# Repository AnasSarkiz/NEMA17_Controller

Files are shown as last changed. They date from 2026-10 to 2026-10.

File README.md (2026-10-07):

# NEMA14 USB-C PD controller

A two-layer tscircuit **hardware prototype** for the STEPperONLINE 14HM11-0404S, using **CH32X035G8U6**, two separate USB-C receptacles, and four mounting holes. Manufacturing release is blocked until the motor's rear geometry is verified and the prototype is tested. See `artifacts/drc-report.json` for the current routed-board checks; a generated Gerber ZIP is not a release approval.

| Item | Design |
| --- | --- |
| Motor | 35 × 35 × 28 mm, bipolar, 0.9°, 0.4 A/phase, 10 V, 11 N·cm — specifications from the supplied product listing |
| Board | 35 × 35 mm, two copper layers, 1.6 mm FR-4; all components assembled on top |
| USB-C placement | PD opening flush with left edge; data opening flush with right edge; pads and shell anchors inside PCB |
| Mounting | Four Ø3.2 mm non-plated holes at (±13, ±13) mm; 26 mm square pitch; 5.4 mm square copper/component exclusions |
| MCU | CH32X035G8U6, QFN-28 plus grounded exposed pad; internal oscillator |
| Power USB-C | CH224K fixed request for **15 V**: CFG1 low, CFG2/CFG3 high |
| Computer USB-C | USB 2.0 full-speed D+/D− and two 5.1 kΩ CC pull-downs; USBLC6-2SC6 ESD protection |
| Driver | A4988SETTR-T, fixed 1/16 microsteps, regulated phase current |
| Current | 0.351 A nominal peak; 0.24 Ω sense resistors; 39 kΩ/10 kΩ VREF divider |
| Motor connection | Four plated wire-solder holes: A+, A−, B+, B− |
| Programming | Data USB-C via ROM ISP with 4.7 kΩ BOOT jumper; WCH-LinkE debug pads retained |
| Tools | tscircuit 0.0.2764, CLI 0.1.2261; latest npm versions at setup time, pinned in lockfile |

## View and work on the design

```sh
cd /workspace/NEMA17_Controller
npm ci --legacy-peer-deps --cache /workspace/.npm-cache
npm run dev
npm run check
```

`npm run dev` starts the tscircuit editor. The editor source is `src/board.tsx`; the final, saved copper is `artifacts/board.circuit.json`. Editor autorouting can produce different traces; **do not replace the checked copper without rerunning DRC**. The original tscircuit autorouting, including its diagnosed violations, is retained as `artifacts/autorouted.circuit.json` for comparison.

The routing workflow is recorded in `docs/routing.md`. Render the saved final layout with `npm run render`; this preserves routes. `npm run autoroute` runs tscircuit's local autorouter afresh. The final fallback uses freerouting 2.0.1 and the physically accurate DSN exporter in `scripts/export-supplier-router.py`; both the DSN and SES are saved. Checks run against actual copper, not the existence of a server or a generated file.

## Electrical choices

The A4988 regulates coil current, so 15 V supply does not apply a constant 15 V to the 10 V-rated windings. VREF = 3.3 × 10/(39+10) = 0.6735 V; I_peak = VREF/(8 × 0.24 Ω) = 0.3508 A. The tolerance/engineering allowance estimates 0.3969 A; current and temperature must be measured on a prototype. The motor has 400 full steps/revolution, giving 6,400 commanded microsteps/revolution.

The motor bridge draws only from `PD_VBUS`. Two B5819W Schottky diodes OR `PD_VBUS` and `DATA_VBUS` into a 30 V-rated HT7533-1 3.3 V regulator. This lets the MCU enumerate from the computer alone and prevents 15 V backfeeding into the computer's VBUS. Both ports share signal ground. The linear regulator supplies only logic; motor current bypasses it. Driver SLEEP has a pull-down and ENABLE_N a pull-up, so the bridge remains disabled until firmware deliberately enables it.

Use a USB PD supply advertising a 15 V PDO. The CH224K requests 15 V; it cannot force an unsupported supply to deliver it. CH224K PG is an **active-low** good-power indication. Firmware must also check measured motor voltage before enabling the bridge. DATA_PRESENT permits USB attachment only when computer VBUS is present. See `docs/firmware-interface.md`; no USB motor-control firmware or physical enumeration result is claimed by this hardware-only prototype.

## Rear mounting decision

The supplied listing establishes the motor envelope; it does **not** establish rear screw threads or rear-hole pitch. The [manufacturer drawing](https://www.omc-stepperonline.com/download/14HM11-0404S.pdf) confirms 26 ± 0.2 mm pitch and four M3 threads, minimum 4 mm depth, on the front mounting face; it does not dimension rear attachment holes. The four 26 mm-spaced board holes are provisionally suitable for a separate rear adapter/standoff plate. **They are not asserted to match the motor's rear screws. Do not replace motor end-cap screws or drill the motor from these files.** The mounting drawing explicitly marks the unresolved fit. Rear installation also needs an insulating gap and clearance for motor wiring, any rear shaft/boss, and screw heads. Use an adapter plate after the rear drawing or physical motor is available.

## Cost and release

There are 38 fitted parts and three bare motor/debug/BOOT interfaces, with no purchased PD module, motor-driver module, external crystal, buck inductor, potentiometer, or motor connector. A rough small-volume component allowance is **US$4–7**, excluding PCB, assembly, shipping, motor, and supply. This is an estimate, not a vendor quote or an absolute budget guarantee. Ratings and procurement notes are in `docs/bom.md`.

Before ordering: obtain the motor rear drawing, review the footprint pin numbering and assembly rotations, check the current DRC/short report, then bench-test USB, PD negotiation, disabled start-up, phase current, regeneration, and temperature. The configured install/start instructions are saved as a draft in environment settings; saving that draft does not publish the environment.

## Published project

[tscircuit: NEMA14_CH32X035G8U6](https://tscircuit.com/AnasSarkiz/NEMA14_CH32X035G8U6). GitHub rename to the same exact name is pending repository-administration authorization; see [publishing notes](docs/publishing.md).

## Supplier models and A4 schematics

[Printable A4 schematic](artifacts/schematic-a4.pdf): 9 numbered landscape sheets with chip-purpose notes and every numbered physical pin. All **38/38 fitted components** use exact JLCPCB imports with native land patterns and OBJ/STEP models. Motor/debug/boot connections are bare PCB pads. See [supplier CAD details](docs/supplier-cad.md) and [the import report](artifacts/jlcpcb-import-report.json).

The GitHub repository is currently [AnasSarkiz/NEMA17_Controller](https://github.com/AnasSarkiz/NEMA17_Controller). Its requested rename to `NEMA14_CH32X035G8U6` is blocked by the GitHub integration (HTTP 403); repository settings must apply it. The project/package name is already correct. Supplier CAD URLs use the existing public repository so they load now.

## USB and final validation

[USB programming procedure](docs/usb-programming.md) · [Validation details](docs/validation.md) · [Browser schematic analysis](artifacts/validation/schematic-analysis-ui.png). Both board variants support boot-mode entry through their Data USB-C port; flashing still requires assembled-hardware validation. Current software checks report zero DRC errors/warnings, zero schematic-placement findings and no Gerber shorts. Application firmware remains a separate task.

The public main entry point is `index.circuit.tsx`, which exports the board from `src/board.tsx`. `index.circuit.json` is the checked saved layout; publication refreshes it from `artifacts/board.circuit.json` and includes both JSON files. `tscircuit.config.json` selects the root source entry and saved-layout preview.

Publication uses the CLI build-output option: `tsci push index.circuit.tsx --include-dist`. Before uploading, the script runs `tsci build index.circuit.json` and verifies that `dist/index/circuit.json` equals the checked saved routing.

## Copper and electrical review

The [electrical review](docs/electrical.md) records power-trace widening, filled grounds, the corrected 100 kΩ/10 kΩ motor-voltage divider, copper-thickness requirements, and remaining prototype tests. Run `npm run check:copper` for the actual saved-segment audit. The [machine-readable report](artifacts/trace-width-review.json) distinguishes isolated tracks from parallel ground-plane paths; software checks do not certify hardware operation.

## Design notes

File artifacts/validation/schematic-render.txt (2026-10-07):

> NEMA14_CH32X035G8U6@1.0.6 render
> bun scripts/render.ts --schematic-only

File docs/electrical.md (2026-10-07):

# Electrical design review

A4988 VREF = 3.3 × 10/(39+10) = 0.6735 V; Itrip = VREF/(8 × 0.24) = 0.3508 A. The native 0.24 Ω, 1%, 125 mW resistors dissipate about 29.5 mW nominally. A deliberately expanded 3.465 V rail budget, 1% resistor bounds and a provisional 5% driver allowance estimate 0.3969 A. This is an engineering budget, not a qualified maximum: the actual driver accuracy, ground bounce and sense-track resistance must be measured. The SMF18A clamp still requires regenerative-energy testing.

## Copper review, 2026-10-07

The checked saved layout, rather than nominal JSX settings, was reviewed. Power/motor tracks were widened only when exact imported pad, via and foreign-track geometry retained at least 0.15 mm clearance. Their centerlines were retained. `artifacts/power-copper-adjustments.json` records each width change; `supplier-routing-adjustments.json` replays the complete result from the saved SES import. Ground pours have 0.20 mm clearance, 0.35 mm edge margin, and no unconnected islands. Components remain top-side assembled.

| Copper | Actual saved width / review |
| --- | --- |
| Motor outputs / sense | About 0.28–0.45 mm, including package escapes; screened at 0.40 A peak |
| PD motor supply | 0.30–0.60 mm; 0.75 A input budget, with a verified single-bridge RP2040 branch screened at 0.40 A |
| Logic supply / switching node | Widened where possible; package escapes remain as small as 0.16 mm; 0.15 A rail / 0.20 A switching budget |
| Ground | 0.16–0.45 mm tracks plus filled ground copper; parallel plane paths must be considered, rather than assuming the entire motor return flows down every ground stub |
| USB / other signals | 0.16 mm; width alone does not establish differential impedance or signal integrity |

Copper screening requires **at least 35 μm finished external copper and 17.5 μm internal copper** where applicable, on 1.6 mm FR-4, with at least 20 μm via barrel plating. These are fabrication requirements, not measurements of a manufactured PCB. IPC-2221 equations use k=0.048 externally and 0.024 internally, with a 30 °C rise screening limit. The report includes each actual segment, layer, current budget and temperature estimate. This approximate method does not model enclosure/motor heating, neck heat spreading, switching pulses, vias or ground-plane current sharing.

The largest isolated non-ground trace estimate is 5.2 °C at its assigned budget. Ground traces covered by the same-net pour are explicitly reported as parallel paths; their isolated-track estimate is not a prediction of actual plane temperature. Ground current sharing and regulator/driver temperatures remain bench checks.

## Voltage sensing correction

R_VM_H/R_VM_L is now **100 kΩ/10 kΩ**, replacing 100 kΩ/22 kΩ. It produces 1.364 V at 15 V; the worst resistor-tolerance value is 3.240 V at a 35 V review envelope. The old divider produced 3.606 V at only 20 V, before tolerance, so motor regeneration could overstress the ADC input. This change reuses JLCPCB C25804 and its unchanged native footprint. **Firmware must multiply VM_SENSE voltage by 11**, with calibration as needed. The 35 V arithmetic envelope is not approval to operate the motor bus at 35 V; the intended supply remains 15 V. Rails, TVS energy and component ratings require transient testing.

## Operation review and remaining tests

CH224K requests 15 V with CFG1/2/3 = 0/1/1; PG is active low. A supply must advertise the requested PDO. Driver ENABLE_N has a pull-up, SLEEP has a pull-down, and firmware must keep the bridge disabled until PG and measured VM are valid. Diode ORing separates host VBUS from PD while permitting logic-only USB power. USB/data ground is shared with motor power.

USB programming entry is wired: WCH ROM ISP through PC17/D+ at cold power-up on CH32; RP2040 ROM USB boot through the flash-CS boot jumper and RUN/reset. This has not been demonstrated on physical hardware. USB routes were checked for continuity and shorts, but were not impedance-qualified or accepted as a length-matched differential pair. Reported per-net copper totals contain connector/ESD branches and must not be interpreted as pair skew. Host-only, PD-only and simultaneous-cable tests, both Type-C orientations, repeated enumeration and actual flashing are required.

At first bring-up, keep the motor disconnected, power through a current-limited source, check all rails and confirm disabled outputs. Then verify 15 V PD negotiation/fallback behavior and absence of host backfeed. Measure 3.3 V ripple and load-step response (plus RP2040 1.1 V and crystal startup), flash over USB, measure both phase currents and sense offsets, and exercise stalled/accelerating/stopping motor cases while watching VM overshoot and driver/regulator temperatures. Test at the intended motor/enclosure temperature. The CH32 linear regulator dissipates roughly (14.6−3.3)×I_logic, or about 0.34 W at 30 mA; the 100 mA part rating alone is not a thermal guarantee. The RP2040 buck's switching/input loop and feedback placement require ripple/stability validation.

No motor-control firmware is present. Rear mounting remains unverified because the motor drawing dimensions only the front face. Manufacturer-level A4988 accuracy, CH224K/HT7533 electrical limits and component transient ratings remain purchasing/release checks; direct manufacturer document retrieval was blocked in this environment. Existing pin/reference and supplier evidence is recorded in `docs/sources.md`. **Manufacturing release remains blocked.**

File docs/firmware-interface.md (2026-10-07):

# Firmware interface (hardware contract; implementation pending)

| Signal | CH32X035G8U6 pad | GPIO | Requirement |
| --- | --- | --- | --- |
| STEP | 5 | PA0 | Timer-driven pulses, ≥2 µs high and ≥2 µs low |
| DIR | 6 | PA1 | Hold stable ≥2 µs before STEP edge |
| PD_GOOD | 7 | PA2 | Active-low CH224K PG; pull-up to 3.3 V |
| DATA_PRESENT | 8 | PA3 | 100 kΩ/100 kΩ divider from computer VBUS |
| VM_SENSE | 9 | PA4 | 100 kΩ/10 kΩ divider; 15 V → 1.364 V; ADC full scale is not a safe overvoltage limit |
| ENABLE_N | 14 | PB3 | High disables driver; hardware default high |
| SLEEP | 15 | PB4 | Low disables bridge/charge pump; hardware default low |
| DCK | 24 | PC19 | WCH two-wire programming clock |
| DIO | 25 | PC18 | WCH two-wire programming data |
| USB D− | 26 | PC16 | USBFS native PHY |
| USB D+ | 27 | PC17 | USBFS native PHY |

CH32X035G8U6 uses 3.3 V supply and its internal 48 MHz oscillator. USB firmware must select the MCU's **3.3 V PHY mode**, detect data-port VBUS, and use the native USB pull-up configuration; do not copy a 5 V-only example unchanged. The fixed PD trigger requires no MCU PD stack.

Startup sequence: initialize STEP low, ENABLE_N high, SLEEP low; read voltage and PG; expose USB only with data VBUS present; require an explicit host command; enable only with PG low and motor supply 13.5–16.5 V; raise SLEEP, wait at least 1 ms for the charge pump, then drive ENABLE_N low. A source without a 15 V PDO must leave the motor disabled. Stop on a lost PD contract, USB disconnect, or command watchdog timeout. Never automatically resume motion after reset.

A proposed USB CDC command interface is `STATUS`, `MOVE <signed microsteps> <microsteps/second>`, `STOP`, and `DISABLE`. Use a timer/state machine rather than blocking delays. Limit acceleration and speed through bench testing; winding current and available torque limit the useful rate. This file is a contract for the next firmware task, not tested firmware. WCH provides `EVT/EXAM/USB/USBFS/DEVICE/SimulateCDC` in its CH32X035 SDK; remove the example's USART2 bridge because PA2 is used here for PD power sensing. PA3 is used for computer-VBUS presence.

For factory ROM USB boot entry, see [USB programming](usb-programming.md). This hardware contract does not supply a motor-control application.

Motor voltage conversion: `VM_V = VM_SENSE_V × 11` for the reviewed 100 kΩ/10 kΩ divider. Update/calibrate firmware accordingly; the former ×(122/22) conversion is obsolete.

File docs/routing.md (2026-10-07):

# Saved supplier-footprint routing

The latest native tscircuit autorouter was run and its result is saved as `artifacts/autorouted.circuit.json`. Remaining violations required the authorized Freerouting fallback. `scripts/export-supplier-router.py` exports exact imported polygon, rectangle, pill and circle pads to `supplier-input.dsn`; Freerouting 2.0.1 output is saved in `supplier-board.ses`. `scripts/import-supplier-session.py supplier` converts that session without replacing supplier footprints.

The CH32 board uses two copper layers. The RP2040 board uses top / inner1 ground / inner2 signals / bottom, with no inner1 signal tracks. RP2040 ground fills have 0.20 mm clearance and 0.35 mm edge margin. Ordinary fallback vias are 0.50/0.25 mm. Two RP2040 QSPI escape vias are 0.40/0.20 mm. Only grounded exposed-pad thermal vias may sit inside pads. All fitted components and paste are on top; through-hole USB shield joints require soldering.

Selected final PCB changes from the fallback session are recorded in `supplier-routing-adjustments.json`. These include thermal-pad contact segments, and on RP2040 a 0.10 mm C_DV50 move, neighboring V1V1/QSPI_SD3 trace adjustments and the completed QSPI_SD0 route. No native supplier land pattern was changed. `replay-supplier-adjustments.py` checks each expected before-record before applying the saved adjustment set.

Validate the final `board.circuit.json` with `npm run check`, the native-geometry `verify-connectivity.py`, `tsci check`, and all-layer 100 pixels/mm Gerber shorts analysis. These checks do not establish controlled impedance, EMC, manufacturing fit or tested hardware operation.

The 2026-10-07 power review widened saved track records without changing their paths and refilled grounded copper on all existing layers. Both variants now have ground fills. `review-power-copper.py` performs clearance-constrained widening; `fill-ground.py` refills native-geometry pours; `audit-trace-widths.py` screens the resulting actual segments. Complete SES-to-final changes remain in the replay proof. Rerouting or replay must also recompile and merge current source metadata so the 10 kΩ motor-sense resistor is retained.

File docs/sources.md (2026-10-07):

# Sources and evidence

- Motor requested by user: https://www.omc-stepperonline.com/nema-14-bipolar-0-9deg-11ncm-15-58oz-in-0-4a-10v-35x35x28mm-4-wires-14hm11-0404s . Manufacturer drawing verified: https://www.omc-stepperonline.com/download/14HM11-0404S.pdf . It confirms 0.40 A/phase, 25 Ω ±10%, 24 mH ±20%, 0.9° steps, and front-face 26 ±0.2 mm M3 mounting pitch. Rear attachment dimensions are absent.
- Official WCH SDK: https://github.com/openwch/ch32x035 . Its Snake board embeds a CH32X035G8U6 symbol and QFN28/4×4/0.4/2.6×2.6 footprint.
- Current KiCad symbols: https://gitlab.com/kicad/libraries/kicad-symbols , inspected revision `e1bb0a65cb243525367c5dc7294665b9fd57fc4d`; `MCU_WCH_RiscV/CH32X035G8U6` and `Interface_USB/CH224K` establish pin mapping and package selection.
- Current KiCad footprints: https://gitlab.com/kicad/libraries/kicad-footprints ; `SSOP-10-1EP_3.9x4.9mm_P1mm_EP2.1x3.3mm` and `SOT-89-3` establish the corrected PD and regulator land dimensions.
- Published PD reference: https://github.com/tomorrow56/CH224K_PDDecoy , `toragi/img/04_Schematics.png` independently confirms CC1 pin7 / CC2 pin6. https://github.com/UNIT-Electronics-MX/unit_proto_power_delivery_decoy_ch224k at `36e92b99cba94163813b383ca9a16cd6f7f6ef62` documents CFG1/2/3 = 0/1/1 for 15 V.
- Driver package/pin reference: https://github.com/adafruit/Adafruit-A4988-Breakout-PCB at `f10f6b1d10aeeabc7a4a3445b81925c0a51d0e45`, Eagle A4983_LOGICAL / QFN28_5MM used on that A4988 carrier. Manufacturer A4988 electrical accuracy/rating review remains required before release. Current pads and models come from the genuine JLCPCB import, not this reference footprint.
- USB footprint: https://github.com/KiCad/kicad-footprints/blob/master/Connector_USB.pretty/USB_C_Receptacle_HRO_TYPE-C-31-M-12.kicad_mod . Converted to TSX using the current tscircuit CLI; physically shared USB pads are represented once.
- Freerouting fallback: https://github.com/freerouting/freerouting/releases/tag/v2.0.1 ; Java21-compatible release JAR downloaded over verified HTTPS. The unsupported GUI-only 1.9.0 attempt was abandoned.

Current fitted parts are genuine JLCPCB imports obtained with `tsci import --jlcpcb --download --use-exact-footprint <C-number>`. `src/jlcpcb-catalog.json` records component-to-part mapping, original import hashes and native OBJ/STEP hashes. No fitted part uses a custom replacement footprint. Earlier KiCad/Eagle references establish pin cross-checks only; they do not define the current supplier land patterns.

Current tools: tscircuit 0.0.2764, CLI 0.1.2261, pinned in the lockfile. WCH evaluation-board reference section 5 documents PC17-high cold-start ROM USB programming. RP2040 and AP63203 manufacturer PDFs used for power/boot/reference checks are cached in the RP2040 project's `references/` directory. The AP63203 PDF is DS41326 Rev 3-2, November 2024, including the fixed-output pin map and PCB layout guidance. Additional direct Allegro/Raspberry Pi document retrieval during this review returned HTTP 403; no new manufacturer qualification is claimed from those failed requests.

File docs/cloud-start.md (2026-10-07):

# Cloud startup

Use the existing `/workspace/NEMA17_Controller` and `/workspace/NEMA14_RP2040` checkouts. Install from lockfiles using `npm ci --legacy-peer-deps`; local scripts supply Bun. `scripts/cloud-install.sh` restores Python routing dependencies in `/workspace/.routing-venv`, verifies locked Git dependency source checksums and Freerouting 2.0.1. Retain TLS/checksum checks.

Run TypeScript, source compilation, saved-board build, native physical connectivity and all-layer Gerber shorts checks. The delivery has 351 trace sections/38 fitted supplier models on CH32 and 519 trace sections/61 fitted models on RP2040; DRC errors and warnings are zero. `npm run build` uses saved copper. `npm run autoroute` writes a separate diagnostic result and does not replace delivery copper.

Use `XDG_CONFIG_HOME=/workspace/.config` for authenticated CLI publication. Reuse configured authentication without printing secrets. Exact JLCPCB imports and OBJ/STEP assets are in `imports/supplier/`; CAD viewers load public GitHub URLs. Native A4 drawings have 9 CH32 and 13 RP2040 pages. The supplier report requires the routing Python environment: `/workspace/.routing-venv/bin/python scripts/report-presentation.py`.

`npm run dev -- --port 5173` starts the saved-board preview. `python3 scripts/schematic-review-ui.py` starts the read-only native A4/CLI findings review UI. Check local HTTP endpoints internally; share the public project links. The official IDE saved-JSON schematic pane is disabled and WebGPU is unavailable here. Restart servers in a fresh task.

Both designs remain unassembled prototypes. Rear-motor fit, physical USB flashing, PD/thermal testing and firmware implementation remain outstanding. The manufacturer drawing gives front mounting only; four 26 mm-pitch holes are for an unverified rear adapter. The CH32 GitHub identity remains AnasSarkiz/NEMA17_Controller because its requested rename returned HTTP 403. Environment draft saving does not activate its configuration; review/save/publish in environment settings. Fresh-task restoration has not been independently tested.

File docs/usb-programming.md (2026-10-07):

# USB programming

1. Disconnect both USB-C cables so the MCU is fully unpowered.
2. Short the two bare `J_BOOT` pads with tweezers. `R_USB_BOOT` (4.7 kΩ) pulls PC17/D+ high, following WCH's reference download circuit.
3. Connect the computer to **J_DATA** while holding the short; release it after power-up.
4. Use WCHISPTool's CH32X035 USB download mode to load a compatible application.
5. Remove the short and power-cycle to run the application.

Source: WCH [CH32X035 official EVT](https://github.com/openwch/ch32x035), `EVT/PUB/CH32x035 Evaluation Board Reference-EN.pdf`, section 5, and `EVT/PUB/CH32X035SCH.pdf`. PC17 is physical pad 27; PC16/D− is pad 26. WCH-LinkE pads remain available. The example USB-IAP application is not preloaded; this procedure targets factory ROM ISP. Both power inputs must be disconnected for cold boot.

The **PD port is motor power only**, requesting 15 V. Programming uses the separate **Data USB-C port**. USB ROM entry connections and physical copper continuity have been checked in CAD. Enumeration, boot-ROM PHY operation at the chosen supply, and actual flashing must still be tested on an assembled prototype. No motor-control firmware has been implemented or preloaded. Keep the motor disconnected during the first flashing/rail checks.

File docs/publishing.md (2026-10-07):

# Publishing

Requested name: `NEMA14_CH32X035G8U6` (case retained).

Public registry project: https://tscircuit.com/AnasSarkiz/NEMA14_CH32X035G8U6 . Publish updates with `npm run publish:tscircuit`; CLI login uses `XDG_CONFIG_HOME=/workspace/.config tsci login`. The configuration includes checked copper in `artifacts/board.circuit.json`. The source-rendered registry preview may autoroute differently; use the saved artifact and Gerbers to review manufactured copper.

GitHub: https://github.com/AnasSarkiz/NEMA17_Controller . Renaming to `AnasSarkiz/NEMA14_CH32X035G8U6` remains blocked: GitHub returned HTTP 403, "Resource not accessible by integration", although account access reports administrator permission. The integration credential needs repository Administration write permission, or the owner can rename in repository Settings. After renaming:

```sh
git remote set-url origin https://github.com/AnasSarkiz/NEMA14_CH32X035G8U6.git
git push origin HEAD:main
```

The registry upload is independent; automatic GitHub linking was rejected because the repository is not accessible to the tscircuit GitHub app installation. Both projects are public. Publication does not imply firmware completion, tested electrical behavior, rear mounting compatibility, or manufacturing approval.

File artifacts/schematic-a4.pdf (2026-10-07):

A | A

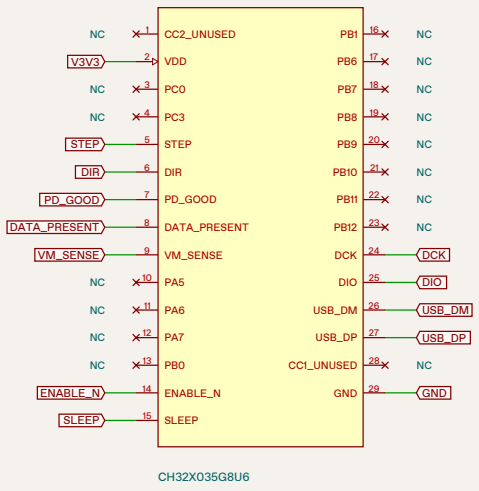
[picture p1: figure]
CC2_UNUSED; VDD; STEP; DIR; PD_GOOD; DATA_PRESENT; VM_SENSE; 14 ENABLE_N; 15 SLEEP; 24 DCK; 25 DIO; 26 USB_DM; 27 USB_DP; 28 CC1_UNUSED; 29 GND; ENABLE_N; SLEEP; DCK; DIO; USB_DM; USB_DP; GND

B | B
C | C
D | D

### U_MCU

## NEMA14_CH32X035G8U6 - USB-C NEMA14 MOTOR CONTROLLER

## COMPONENT PURPOSE

### U_MCU - CH32X035G8U6

USB computer control; generates STEP/DIR. Checks PD voltage before enabling the motor. Internal clock avoids an external crystal.

### U_PD - CH224K

USB-C PD sink requests a 15 V motor supply. PG reports a completed power negotiation.

### U_LDO - HT7533-1

Creates 3.3 V for MCU and driver logic.
Diode OR accepts either USB data power or PD.

### U_DRV - A4988

Two current-regulated bridges drive the coils. STEP/DIR interface; fixed 1/16 microstepping. 0.24 ohm sense resistors set phase current.

### U_ESD - USBLC6-2SC6

Clamps ESD on USB D+ and D- at the data port. VBUS pin references the USB protection diodes.

PD PORT: motor power, 15 V requested. DATA PORT: USB computer control.
Motor: 14HM11-0404S, bipolar, 0.4 A/phase. Prototype: firmware/bench/rear-fit validation pending.

### SHEET 1/9 - U_MCU

Named nets connect across all pages. NC = intentionally unconnected pin.

A | A

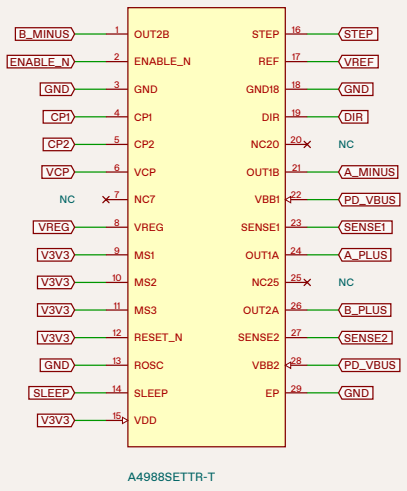
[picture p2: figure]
A4988SETTR-T; OUT2B; ENABLE_N; GND; VCP; VREG; 12 RESET_N; 13 ROSC; 14 SLEEP; 15 VDD; 16 STEP; 17 REF; 18 GND18; 19 DIR; 21 OUT1B; 22 VBB1; 23 SENSE1; 24 OUT1A; 26 OUT2A; 27 SENSE2; 28 VBB2; B_MINUS; SLEEP; STEP; VREF; DIR; A_MINUS; PD_VBUS; SENSE1; A_PLUS; B_PLUS; SENSE2

B | B
C | C
D | D

### U_DRV

## COMPONENT PURPOSE

### U_MCU - CH32X035G8U6

USB computer control; generates STEP/DIR. Checks PD voltage before enabling the motor. Internal clock avoids an external crystal.

### U_PD - CH224K

USB-C PD sink requests a 15 V motor supply. PG reports a completed power negotiation.

### U_LDO - HT7533-1

Creates 3.3 V for MCU and driver logic.
Diode OR accepts either USB data power or PD.

### U_DRV - A4988

Two current-regulated bridges drive the coils. STEP/DIR interface; fixed 1/16 microstepping. 0.24 ohm sense resistors set phase current.

### U_ESD - USBLC6-2SC6

Clamps ESD on USB D+ and D- at the data port. VBUS pin references the USB protection diodes.

PD PORT: motor power, 15 V requested. DATA PORT: USB computer control.
Motor: 14HM11-0404S, bipolar, 0.4 A/phase. Prototype: firmware/bench/rear-fit validation pending.

### SHEET 2/9 - U_DRV

Named nets connect across all pages. NC = intentionally unconnected pin.

A | A
B | B
C | C
D | D

### J_PD

TYPE-C-31-M-12

NC

NC

NC

NC

NC

NC

1 | EH2
2 | EH1
3 | EH4
4 | EH3
5 | SBU2
6 | CC1
7 | DN2
8 | DP1

9 DN1

10 DP2

11 SBU1

12 CC2

13 GND1

14 GND2

15 VBUS1

16 VBUS2

### J_DATA

TYPE-C-31-M-12

NC

NC

1 | EH2
2 | EH1
3 | EH4
4 | EH3
5 | SBU2
6 | CC1
7 | DN2
8 | DP1

9 DN1

10 DP2

11 SBU1

12 CC2

13 GND1

14 GND2

15 VBUS1

16 VBUS2

### U_PD

CH224K

NC

NC

1 | VDD
2 | CFG2
3 | CFG3
4 | DP
5 | DM
6 | CC2

7 CC1

8 VBUS

9 CFG1

10 PG

11 GND

R_PD
1kΩ

C_PD

1uF

R_PG
10kΩ

GND

GND

GND

GND

PD_CC1

PD_CC2

GND

GND

PD_VBUS

PD_VBUS

GND

GND

GND

GND

DATA_CC1

USB_DM

USB_DP

USB_DM

USB_DP

DATA_CC2

GND

GND

DATA_VBUS

DATA_VBUS

PD_VDD

PD_VDD

PD_VDD

PD_CC2

PD_CC1

PD_VBUS

GND

PD_GOOD

GND

PD_VBUS PD_VDD

PD_VDD GND
V3V3 PD_GOOD

## COMPONENT PURPOSE

### U_MCU - CH32X035G8U6

USB computer control; generates STEP/DIR. Checks PD voltage before enabling the motor. Internal clock avoids an external crystal.

### U_PD - CH224K

USB-C PD sink requests a 15 V motor supply. PG reports a completed power negotiation.

### U_LDO - HT7533-1

Creates 3.3 V for MCU and driver logic.
Diode OR accepts either USB data power or PD.

### U_DRV - A4988

Two current-regulated bridges drive the coils. STEP/DIR interface; fixed 1/16 microstepping. 0.24 ohm sense resistors set phase current.

### U_ESD - USBLC6-2SC6

Clamps ESD on USB D+ and D- at the data port. VBUS pin references the USB protection diodes.

PD PORT: motor power, 15 V requested. DATA PORT: USB computer control.
Motor: 14HM11-0404S, bipolar, 0.4 A/phase. Prototype: firmware/bench/rear-fit validation pending.

### SHEET 3/9 - J_PD, J_DATA, U_PD, R_PD, C_PD, R_PG

Named nets connect across all pages. NC = intentionally unconnected pin.

A | A
B | B
C | C
D | D

C_MCU

100nF

C_LOGIC

4.7uF

R_CC1
5.1kΩ

R_CC2
5.1kΩ

R_USB_SENSE_H
100kΩ

R_USB_SENSE_L
100kΩ

V3V3 GND

V3V3 GND

DATA_CC1 GND

DATA_CC2 GND

DATA_VBUS DATA_PRESENT

DATA_PRESENT GND

## COMPONENT PURPOSE

### U_MCU - CH32X035G8U6

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

### U_PD - CH224K

USB-C PD sink requests a 15 V motor supply. PG reports a completed power negotiation.

### U_LDO - HT7533-1

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

### U_DRV - A4988

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

### U_ESD - USBLC6-2SC6

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

### SHEET 4/9 - C_MCU, C_LOGIC, R_CC1, R_CC2, R_USB_SENSE_H, R_USB_SENSE_L

Named nets connect across all pages. NC = intentionally unconnected pin.

A | A
B | B
C | C
D | D

R_VM_H
100kΩ

R_VM_L
10kΩ

C_VM_SENSE

10nF

### U_LDO

HT7533-1

1 | GND
2 | VIN

3 VOUT

D_PD | D_DATA PD_VBUS VM_SENSE | VM_SENSE GND VM_SENSE GND

GND

LOGIC_IN

V3V3

PD_VBUS | LOGIC_IN | DATA_VBUS | LOGIC_IN

## COMPONENT PURPOSE

### U_MCU - CH32X035G8U6

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

### U_PD - CH224K

USB-C PD sink requests a 15 V motor supply. PG reports a completed power negotiation.

### U_LDO - HT7533-1

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

### U_DRV - A4988

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

### U_ESD - USBLC6-2SC6

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

### SHEET 5/9 - R_VM_H, R_VM_L, C_VM_SENSE, U_LDO, D_PD, D_DATA

Named nets connect across all pages. NC = intentionally unconnected pin.

A | A
B | B
C | C
D | D

C_LDO_IN

1uF

C_LDO_OUT

4.7uF

C_CP

100nF

C_VCP

100nF

C_VREG

220nF

C_DRV_LOGIC

100nF

LOGIC_IN GND

V3V3 GND

CP1 | CP2

VCP PD_VBUS

VREG GND

V3V3 GND

## COMPONENT PURPOSE

### U_MCU - CH32X035G8U6

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

### U_PD - CH224K

USB-C PD sink requests a 15 V motor supply. PG reports a completed power negotiation.

### U_LDO - HT7533-1

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

### U_DRV - A4988

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

### U_ESD - USBLC6-2SC6

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

### SHEET 6/9 - C_LDO_IN, C_LDO_OUT, C_CP, C_VCP, C_VREG, C_DRV_LOGIC

Named nets connect across all pages. NC = intentionally unconnected pin.

A | A
B | B
C | C
D | D

C_VM

100nF

C_BULK

47uF

R_SA
240mΩ

R_SB
240mΩ

R_REF_H
39kΩ

R_REF_L
10kΩ

PD_VBUS GND

PD_VBUS GND

SENSE1 GND

SENSE2 GND

V3V3 VREF

VREF GND

## COMPONENT PURPOSE

### U_MCU - CH32X035G8U6

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

### U_PD - CH224K

USB-C PD sink requests a 15 V motor supply. PG reports a completed power negotiation.

### U_LDO - HT7533-1

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

### U_DRV - A4988

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

### U_ESD - USBLC6-2SC6

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

### SHEET 7/9 - C_VM, C_BULK, R_SA, R_SB, R_REF_H, R_REF_L

Named nets connect across all pages. NC = intentionally unconnected pin.

A | A
B | B
C | C
D | D

C_REF

10nF

R_ENABLE
100kΩ

R_SLEEP
100kΩ

### J_MOTOR

PCB solder interface

1 | A_PLUS
2 | A_MINUS

3 B_PLUS

4 B_MINUS

### J_DEBUG

PCB solder interface

1 | VDD
2 | GND

3 DCK

4 DIO

### U_ESD

USBLC6-2SC6

1 | DP1
2 | GND
3 | DM1

4 DM2

5 VBUS

6 DP2

VREF GND
V3V3 ENABLE_N

SLEEP GND

A_PLUS

A_MINUS

B_PLUS

B_MINUS

V3V3

GND

DCK

DIO

USB_DP

GND

USB_DM

USB_DM

DATA_VBUS

USB_DP

## COMPONENT PURPOSE

### U_MCU - CH32X035G8U6

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

### U_PD - CH224K

USB-C PD sink requests a 15 V motor supply. PG reports a completed power negotiation.

### U_LDO - HT7533-1

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

### U_DRV - A4988

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

### U_ESD - USBLC6-2SC6

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

### SHEET 8/9 - C_REF, R_ENABLE, R_SLEEP, J_MOTOR, J_DEBUG, U_ESD

Named nets connect across all pages. NC = intentionally unconnected pin.

A | A
B | B
C | C
D | D

### D_TVS

SMF18A

R_USB_BOOT
4.7kΩ

### J_BOOT

PCB solder interface

### 1 BOOT 2 USB_DP GND PD_VBUS

V3V3 BOOT

BOOT USB_DP

## COMPONENT PURPOSE

### U_MCU - CH32X035G8U6

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

### U_PD - CH224K

USB-C PD sink requests a 15 V motor supply. PG reports a completed power negotiation.

### U_LDO - HT7533-1

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

### U_DRV - A4988

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

### U_ESD - USBLC6-2SC6

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

### SHEET 9/9 - D_TVS, R_USB_BOOT, J_BOOT

Named nets connect across all pages. NC = intentionally unconnected pin.

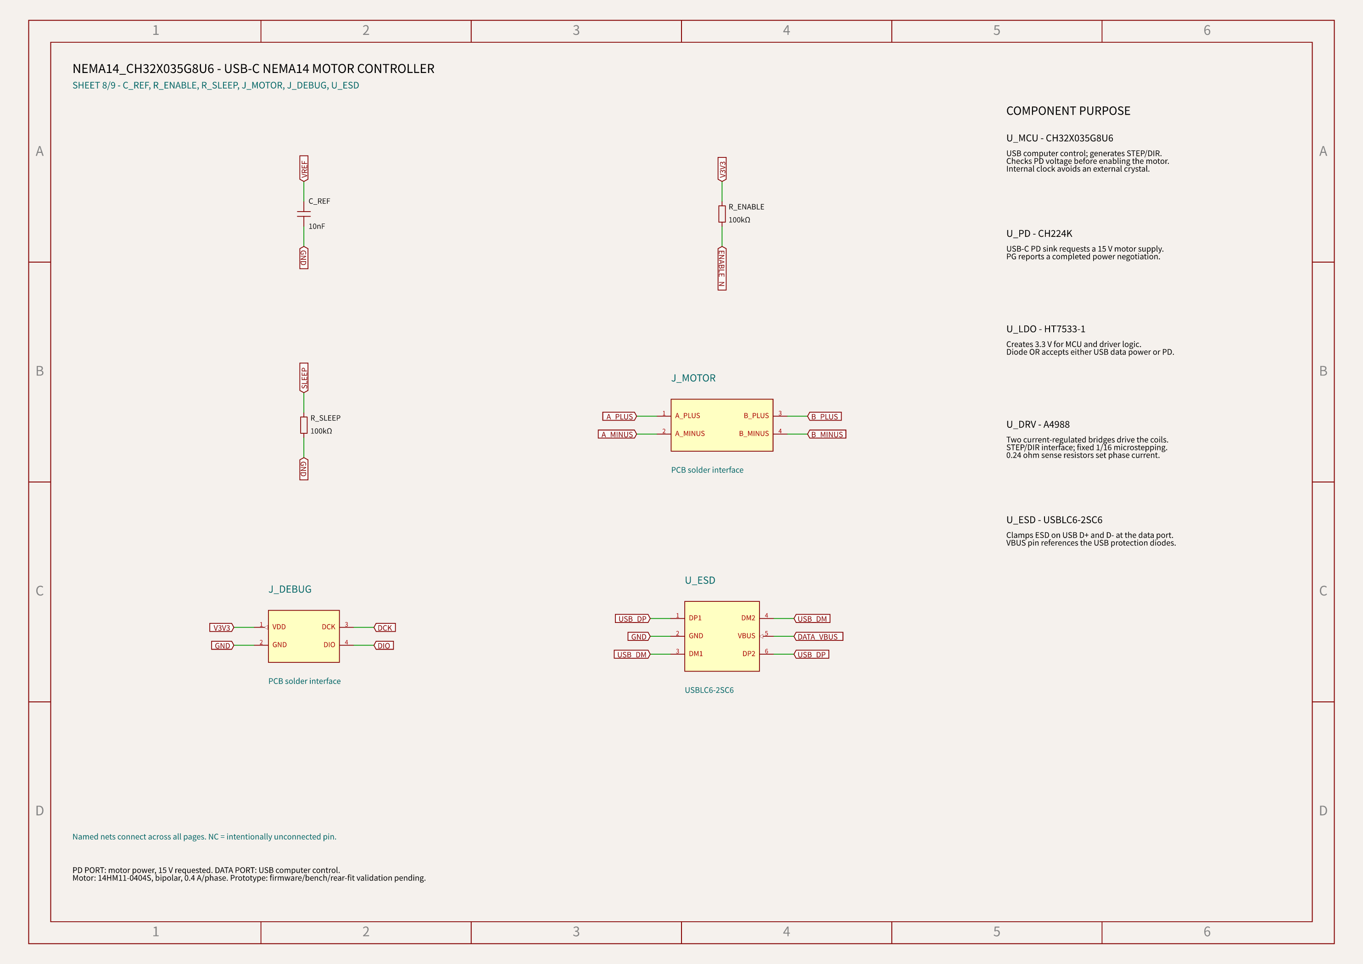
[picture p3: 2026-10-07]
artifacts/schematic-a4-page-08.png

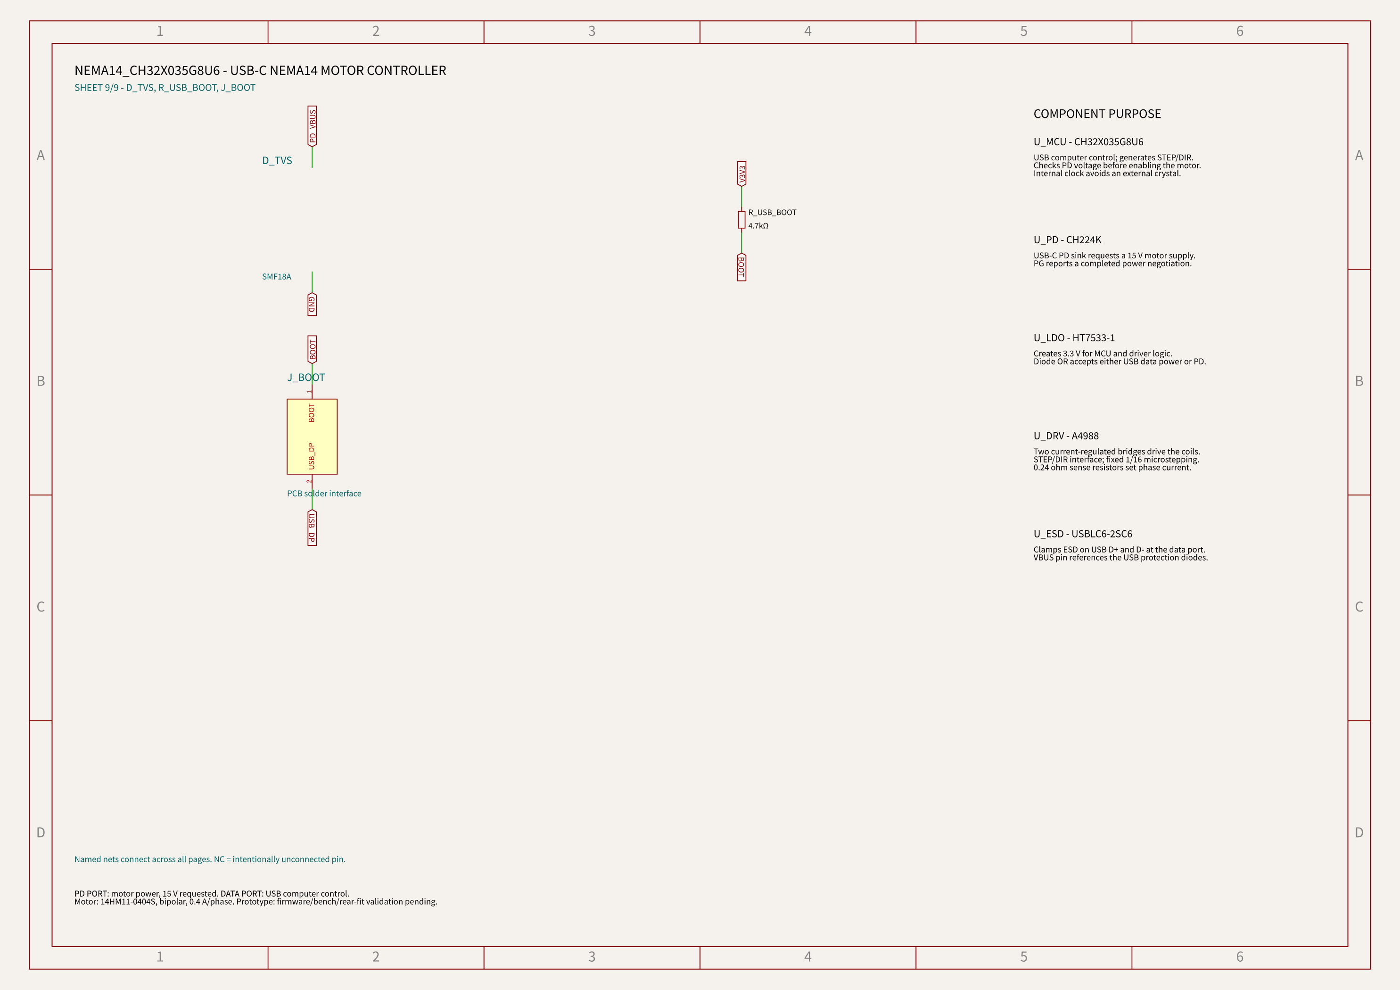
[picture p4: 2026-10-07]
artifacts/schematic-a4-page-09.png

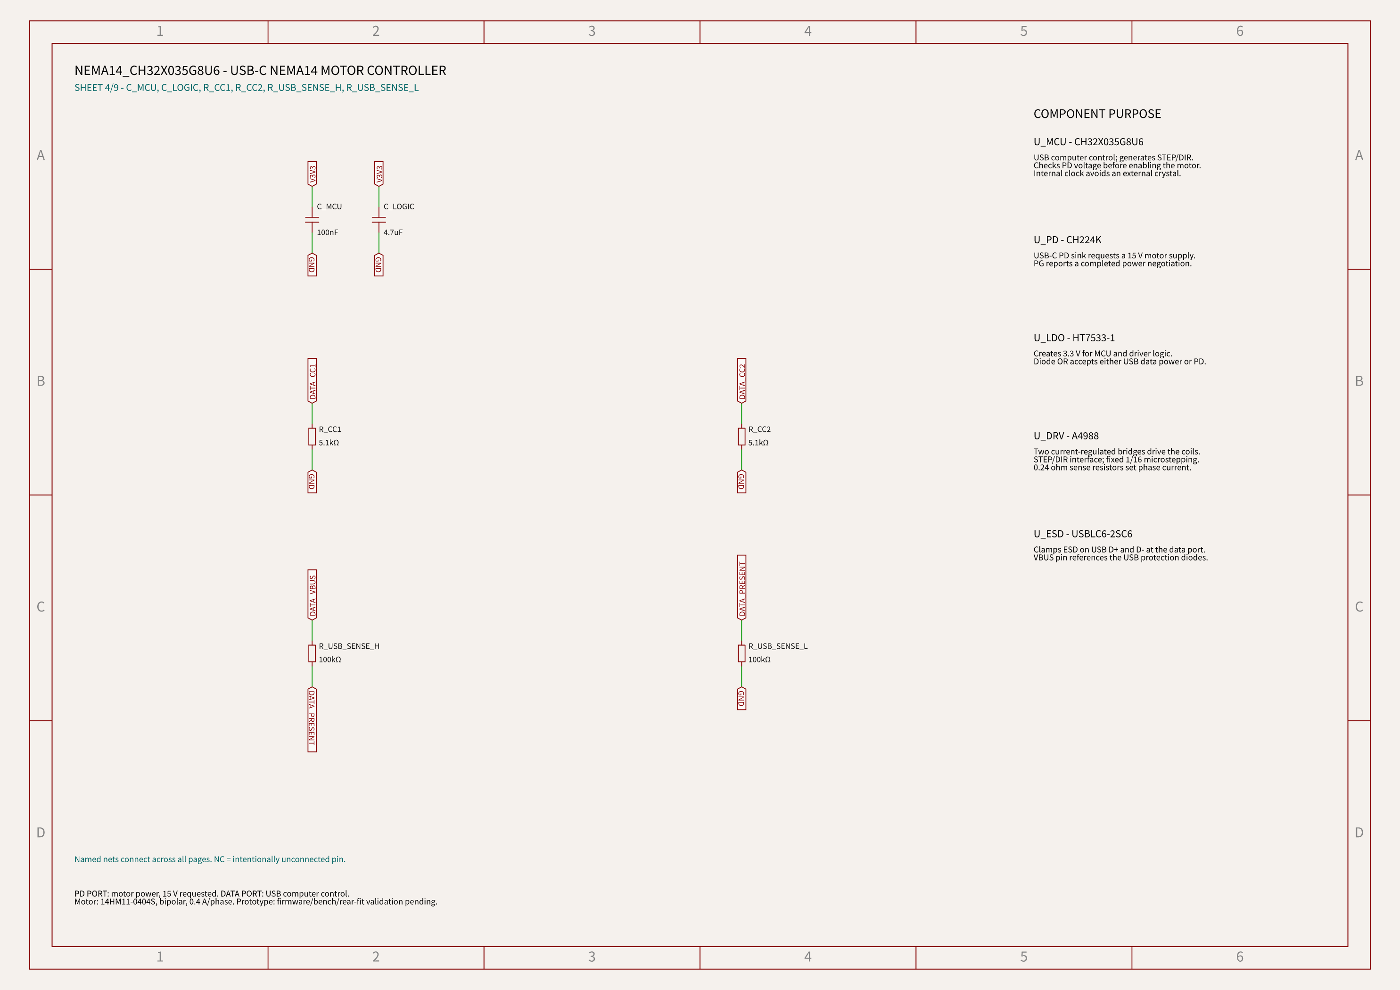
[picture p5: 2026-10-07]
artifacts/schematic-a4-page-04.png

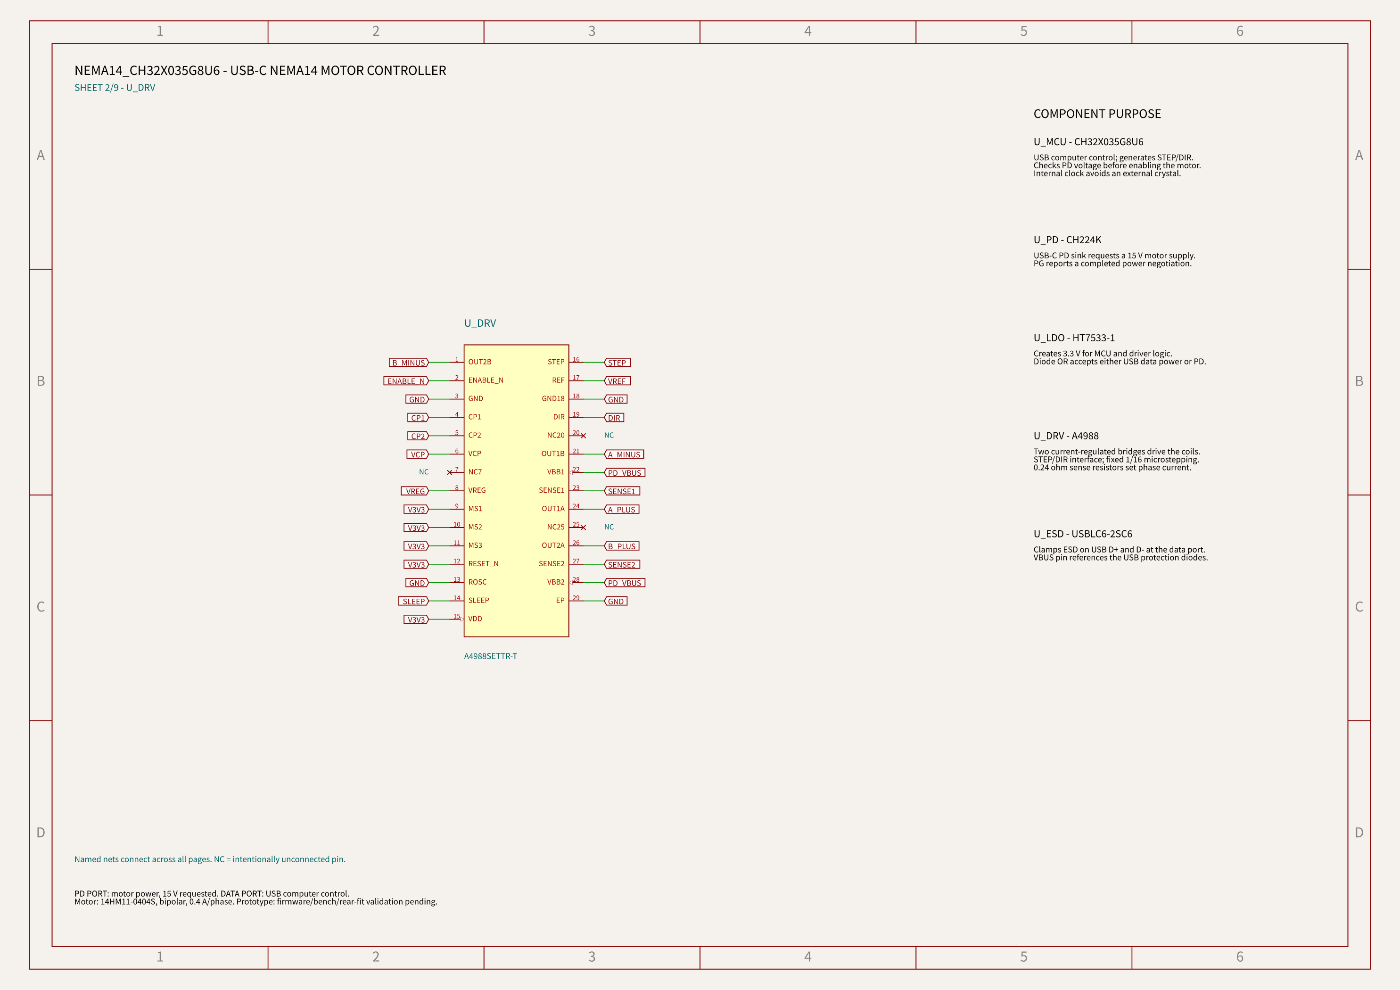
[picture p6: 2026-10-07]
artifacts/schematic-a4-page-02.png

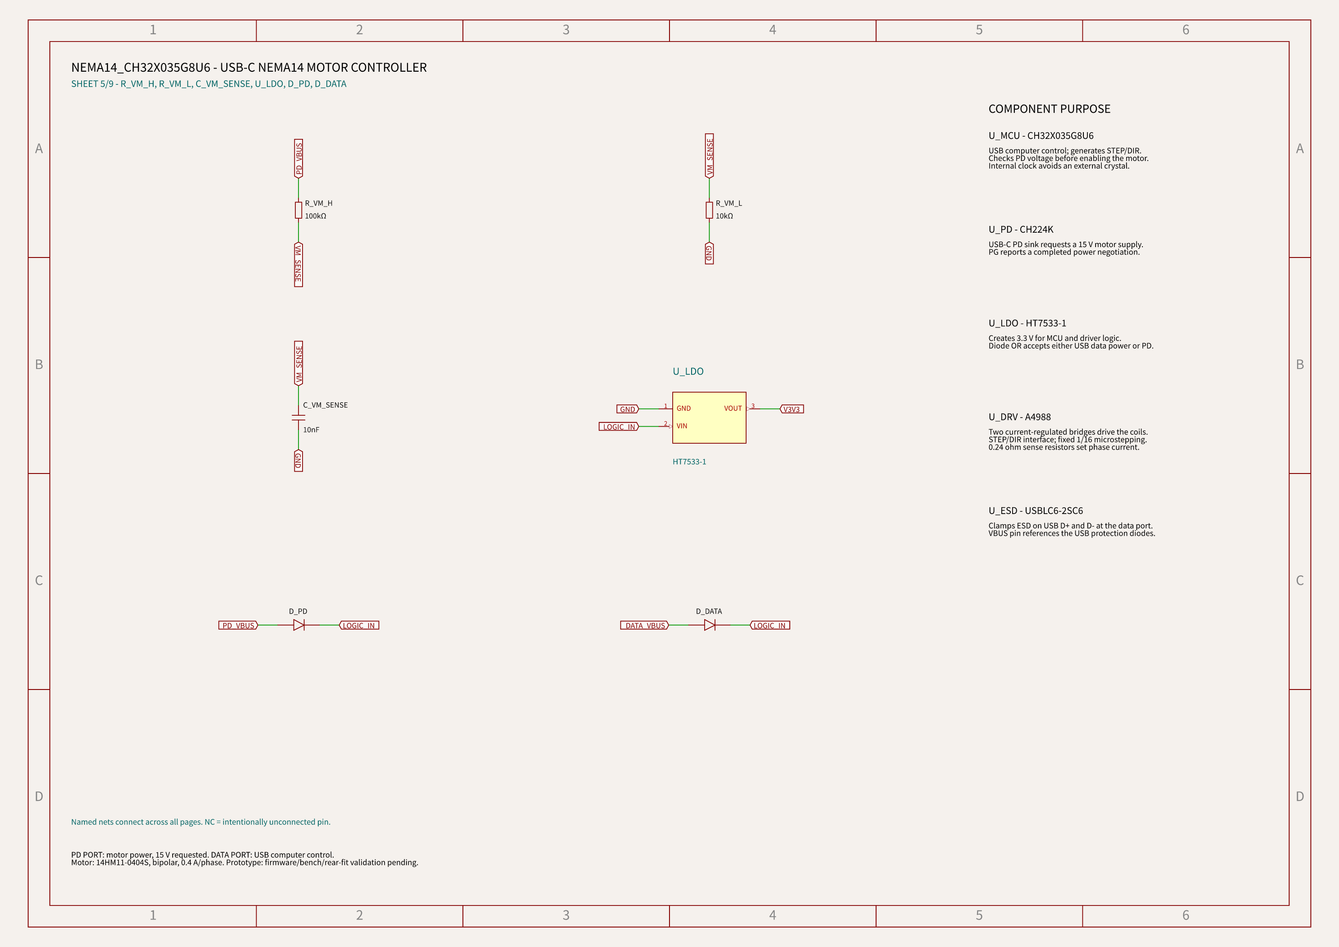
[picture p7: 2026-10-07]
artifacts/schematic-a4-page-05.png

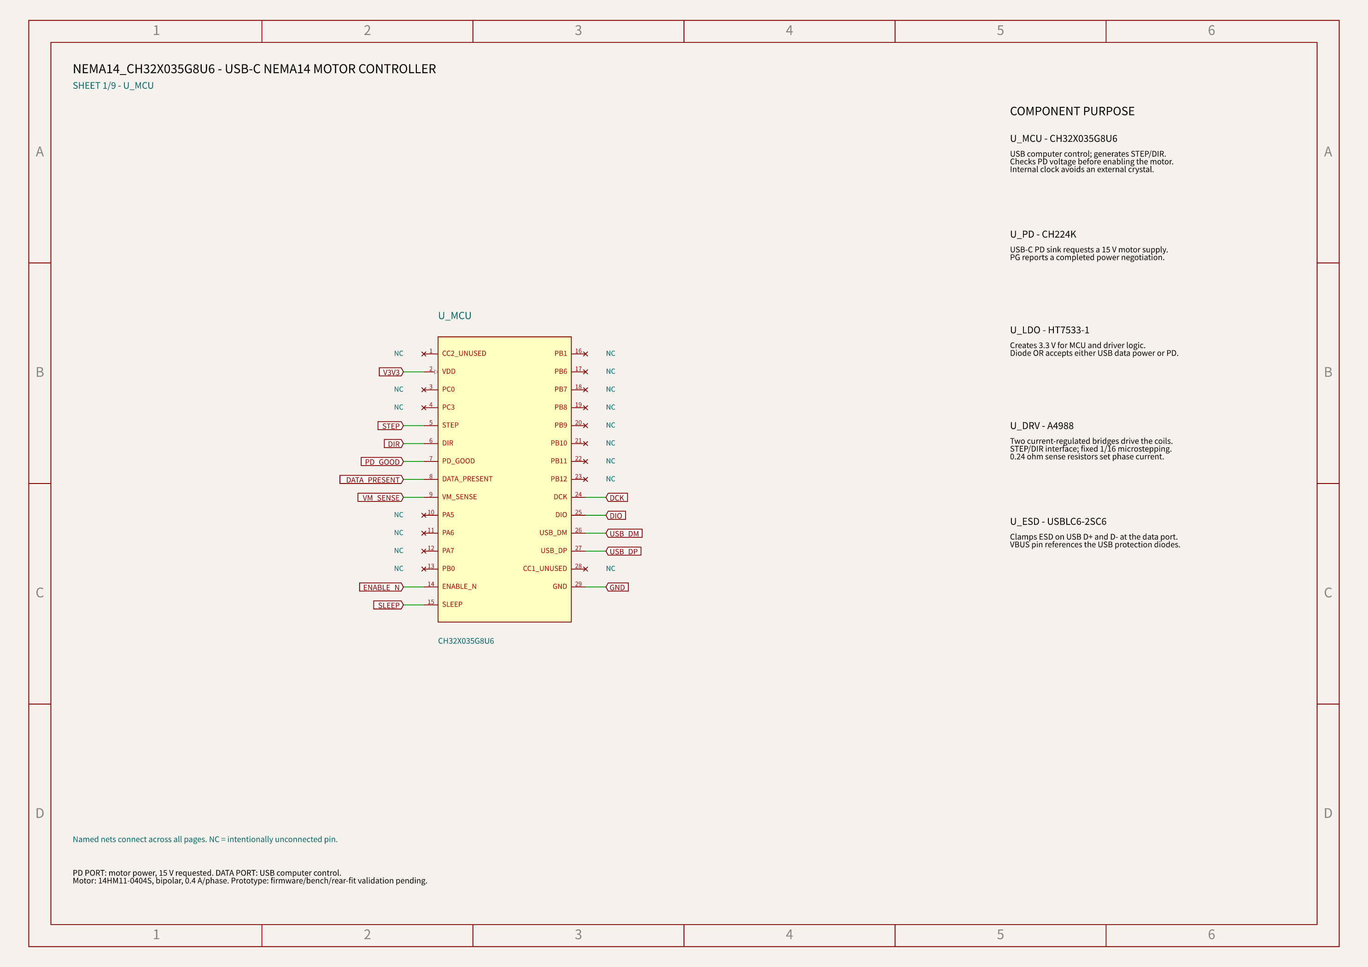
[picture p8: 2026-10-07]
artifacts/schematic-a4-page-01.png

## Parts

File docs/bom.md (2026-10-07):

# Procurement and ratings

[The supplier BOM](../artifacts/bom.csv) and [import report](../artifacts/jlcpcb-import-report.json) identify every fitted part. All supplier land patterns and OBJ/STEP assets are included under `imports/supplier/`. Do not substitute parts without reviewing pinout, ratings and land pattern.

R_PD is C441922 / ERJPA3F1001V, 1 kΩ 1%, 0.25 W 0603. R_SA/R_SB are C2930216 / FRL0805FR240TS, 0.24 Ω 1%, 125 mW 0805. R_REF_H/R_REF_L are 39k/10k. C_BULK is C72522 / RVT1V470M0605, 47 µF 35 V, SMD 6.3 × 5.4 mm. USB receptacles are C165948 / TYPE-C-31-M-12. Both Schottkys are C8598 / B5819W SL, 40 V.

Capacitor effective capacitance, regulator stability, thermal behavior and regenerative-energy handling require prototype checks. BOM cost estimates are allowances, not current distributor quotations. Motor/debug/boot use bare solder pads. Assembly is top only, with USB shell plated joints requiring soldering.

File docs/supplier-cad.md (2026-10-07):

# JLCPCB imports and printable schematics

Every fitted component uses a supplier component created with `tsci import --jlcpcb --download --use-exact-footprint C<number>`. `src/jlcpcb-catalog.json` maps every reference to its exact JLCPCB part and records original import/model hashes. The active component resolver in `src/supplier-parts.tsx` renders the imported JSX; it rejects custom footprint and CAD overrides. Unused generic component files have been removed.

`imports/supplier/` contains the native TSX, unchanged original `.tsx.original`, OBJ and STEP files. Active TSX only adds React compatibility, public GitHub model URLs and a CAD anchor correction for asymmetric pad bounds. Imported footprint JSX is checked byte for byte against the original. No model vertices or supplier footprints have been resized or translated. Public raw GitHub URLs keep large CAD assets outside the registry upload limit.

Both USB receptacles are **C165948 / TYPE-C-31-M-12**. All 16 numbered supplier contacts, including four shield tabs, use the actual land pattern. Their model mating planes are exactly X = −17.5 and +17.5 mm. Model bounds are checked against native courtyards. Coordinate checks do not establish physical rear-motor fit.

Motor, debug and BOOT connections are bare PCB solder interfaces. They have no fitted component to import or model. The four mounting holes are PCB features.

The exact sense resistors are **C2930216 / FRL0805FR240TS**, 0.24 Ω, 1%, 125 mW. A 39k/10k VREF divider sets about 0.351 A nominal peak phase current; estimated sense dissipation is 29.5 mW. The bulk capacitor is **C72522 / RVT1V470M0605**, 47 µF, 35 V. Verify current, thermal behavior and capacitor bias on an assembled prototype.

Native numbered landscape A4 sheets include every physical pin and chip-purpose text. `report-presentation.py` verifies original imported footprint JSX, supplier IDs/MPNs, both CAD assets and hashes, 3D placement bounds, USB opening planes, A4 dimensions and pin/net coverage.

CH224K supply resistor R_PD uses **C441922 / ERJPA3F1001V**, 1 kΩ, 0603, 0.25 W, with its exact imported land pattern. The higher power rating covers dissipation from dropping the requested motor supply to PD logic VDD.

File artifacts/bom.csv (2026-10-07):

Reference | MPN | JLCPCB part | Value | Voltage rating (V) | Tolerance | PCB X mm | PCB Y mm | Rotation deg | Assembly side | Review note
J_PD | TYPE-C-31-M-12 | C165948 |  |  |  | -12.57501465 | 4.5 | 270 | top | native supplier import with OBJ and STEP
J_DATA | TYPE-C-31-M-12 | C165948 |  |  |  | 12.57501465 | 4.5 | 90 | top | native supplier import with OBJ and STEP
U_PD | CH224K | C970725 |  |  |  | -3.4000000000000004 | 8.2 | 270 | top | native supplier import with OBJ and STEP
R_PD | ERJPA3F1001V | C441922 | 1kΩ |  |  | -8.5 | 11.7 | 0 | top | native supplier import with OBJ and STEP
C_PD | CL10A105KB8NNNC | C15849 | 1uF |  |  | -5.5 | 11.7 | 0 | top | native supplier import with OBJ and STEP
R_PG | 0603WAF1002T5E | C25804 | 10kΩ |  |  | -0.5 | 11.8 | 0 | top | native supplier import with OBJ and STEP
U_MCU | CH32X035G8U6 | C7437027 |  |  |  | 4.9993 | 1.5 | 270 | top | native supplier import with OBJ and STEP
C_MCU | CC0603KRX7R9BB104 | C14663 | 100nF |  |  | 5.6 | -3.4 | 0 | top | native supplier import with OBJ and STEP
C_LOGIC | CL21A475KBQNNNE | C98192 | 4.7uF |  |  | 11 | -3.4999999999999996 | 90 | top | native supplier import with OBJ and STEP
R_CC1 | 0603WAF5101T5E | C23186 | 5.1kΩ |  |  | 5.5 | 10.5 | 0 | top | native supplier import with OBJ and STEP
R_CC2 | 0603WAF5101T5E | C23186 | 5.1kΩ |  |  | 8.5 | 12 | 0 | top | native supplier import with OBJ and STEP
R_USB_SENSE_H | 0603WAF1003T5E | C25803 | 100kΩ |  |  | 6.2 | 14 | 0 | top | native supplier import with OBJ and STEP
R_USB_SENSE_L | 0603WAF1003T5E | C25803 | 100kΩ |  |  | 2.1 | 6.5 | 0 | top | native supplier import with OBJ and STEP
R_VM_H | 0603WAF1003T5E | C25803 | 100kΩ |  |  | -0.5 | 14 | 0 | top | native supplier import with OBJ and STEP
R_VM_L | 0603WAF1002T5E | C25804 | 10kΩ |  |  | 3 | 14 | 0 | top | native supplier import with OBJ and STEP
C_VM_SENSE | CL10B103KB8NNNC | C1589 | 10nF |  |  | 2.6 | 5 | 0 | top | native supplier import with OBJ and STEP
U_LDO | HT7533-1 | C14289 |  |  |  | -5.000000000000001 | -1.6491999999999998 | 270 | top | native supplier import with OBJ and STEP
D_PD | B5819W SL | C8598 |  |  |  | -5 | 3.5 | 0 | top | native supplier import with OBJ and STEP
D_DATA | B5819W SL | C8598 |  |  |  | 0 | 2.8 | 90 | top | native supplier import with OBJ and STEP
C_LDO_IN | CL21B105KBFNNNE | C28323 | 1uF |  |  | -6.5 | -7.8 | 180 | top | native supplier import with OBJ and STEP
C_LDO_OUT | CL21A475KBQNNNE | C98192 | 4.7uF |  |  | -5.5 | -5.8 | 0 | top | native supplier import with OBJ and STEP
U_DRV | A4988SETTR-T | C38437 |  |  |  | 0.00010000000000021103 | -8.0001 | 270 | top | native supplier import with OBJ and STEP
C_CP | CC0603KRX7R9BB104 | C14663 | 100nF |  |  | -4.7 | -9.6 | 0 | top | native supplier import with OBJ and STEP
C_VCP | CC0603KRX7R9BB104 | C14663 | 100nF |  |  | -4.1 | -11.8 | 270 | top | native supplier import with OBJ and STEP
C_VREG | CL10B224KA8NNNC | C21120 | 220nF |  |  | -2 | -12.3 | 0 | top | native supplier import with OBJ and STEP
C_DRV_LOGIC | CC0603KRX7R9BB104 | C14663 | 100nF |  |  | 4.7 | -10 | 0 | top | native supplier import with OBJ and STEP
C_VM | CC0805KRX7R9BB104 | C49678 | 100nF |  |  | 0.5000000000000001 | -3.3 | 0 | top | native supplier import with OBJ and STEP
C_BULK | RVT1V470M0605 | C72522 | 47uF |  |  | -12.05 | -5.4 | 90 | top | native supplier import with OBJ and STEP
R_SA | FRL0805FR240TS | C2930216 | 240mΩ |  |  | 6.8 | -12.6 | 90 | top | native supplier import with OBJ and STEP
R_SB | FRL0805FR240TS | C2930216 | 240mΩ |  |  | -6.800000000000001 | -13.7 | 0 | top | native supplier import with OBJ and STEP
R_REF_H | 0603WAF3902T5E | C23153 | 39kΩ |  |  | 6 | -5.5 | 0 | top | native supplier import with OBJ and STEP
R_REF_L | 0603WAF1002T5E | C25804 | 10kΩ |  |  | 6 | -7.8 | 0 | top | native supplier import with OBJ and STEP
C_REF | CL10B103KB8NNNC | C1589 | 10nF |  |  | 11.8 | -7 | 0 | top | native supplier import with OBJ and STEP
R_ENABLE | 0603WAF1003T5E | C25803 | 100kΩ |  |  | -0.5 | -0.5 | 0 | top | native supplier import with OBJ and STEP
R_SLEEP | 0603WAF1003T5E | C25803 | 100kΩ |  |  | -6 | 13.5 | 0 | top | native supplier import with OBJ and STEP
J_MOTOR |  |  |  |  |  | 0 | -15.5 | 0 | top | bare PCB interface
J_DEBUG |  |  |  |  |  | 7.25 | -15.5 | 0 | top | bare PCB interface
U_ESD | USBLC6-2SC6 | C2687116 |  |  |  | 5.5 | 7.5 | 270 | top | native supplier import with OBJ and STEP
D_TVS | SMF18A | C19077512 |  |  |  | -7 | 15.6 | 180 | top | native supplier import with OBJ and STEP
R_USB_BOOT | 0402WGF4701TCE | C25900 | 4.7kΩ |  |  | 2.7 | 10.1 | 0 | top | native supplier import with OBJ and STEP
J_BOOT |  |  |  |  |  | 1.7000000000000002 | 11.9 | 0 | top | bare PCB interface

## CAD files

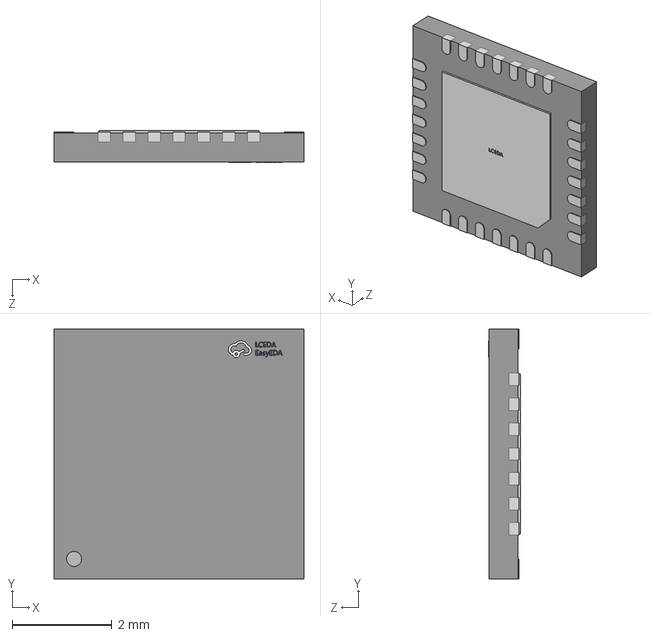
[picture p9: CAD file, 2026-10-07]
imports/supplier/A4988SETTR_T/A4988SETTR_T.step
5.00 x 5.00 x 0.631 mm

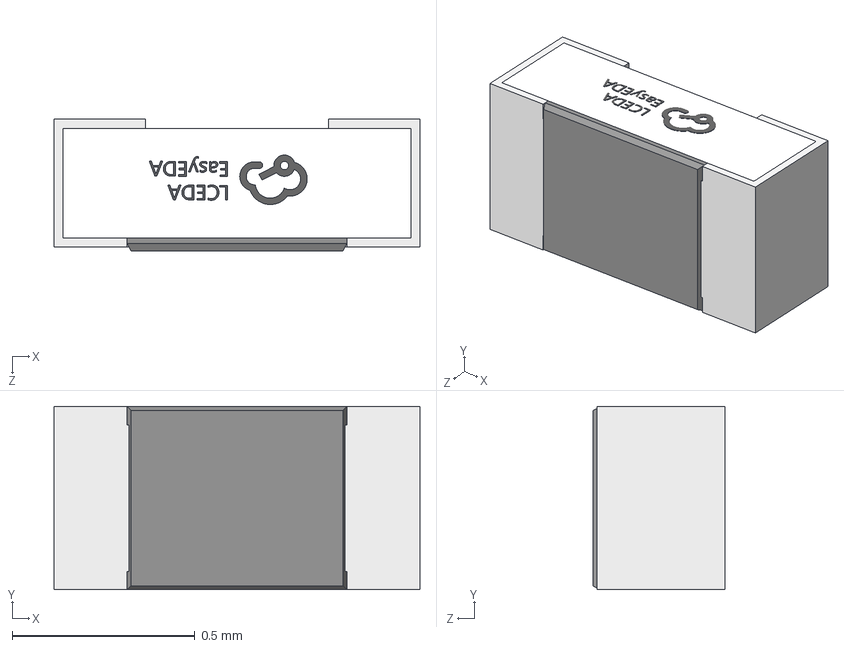
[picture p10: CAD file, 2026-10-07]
imports/supplier/A_0402WGF4701TCE/A_0402WGF4701TCE.step
1.00 x 0.501 x 0.36 mm

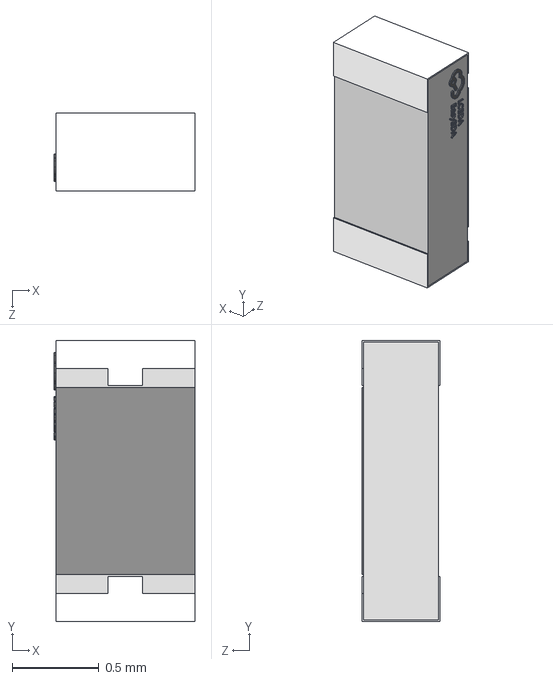
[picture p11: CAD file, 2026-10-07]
imports/supplier/A_0603WAF1001T5E/A_0603WAF1001T5E.step
0.81 x 1.62 x 0.45 mm

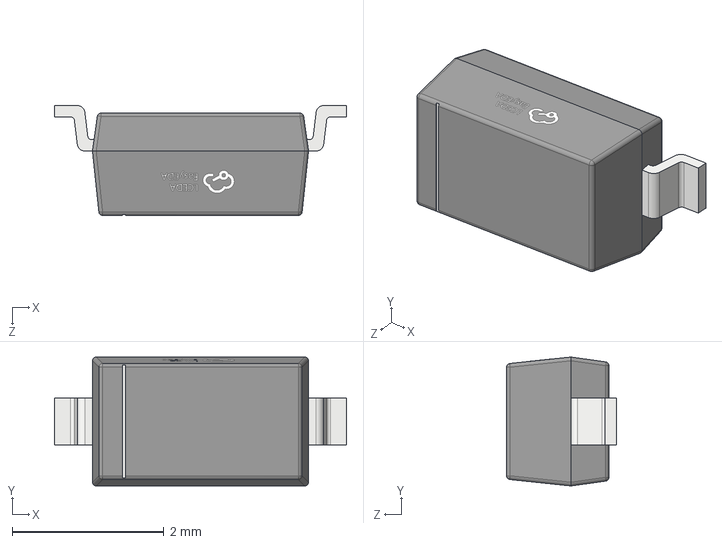
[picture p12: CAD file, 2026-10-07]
imports/supplier/B5819W_SL/B5819W_SL.step
3.85 x 1.70 x 1.45 mm

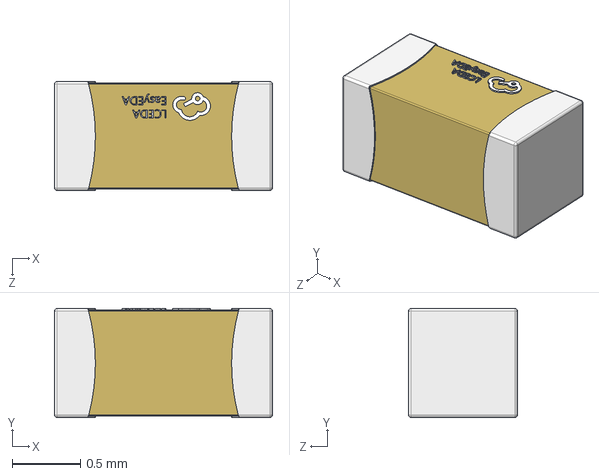
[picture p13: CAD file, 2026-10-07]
imports/supplier/CC0603KRX7R9BB104/CC0603KRX7R9BB104.step
1.60 x 0.8 x 0.8 mm

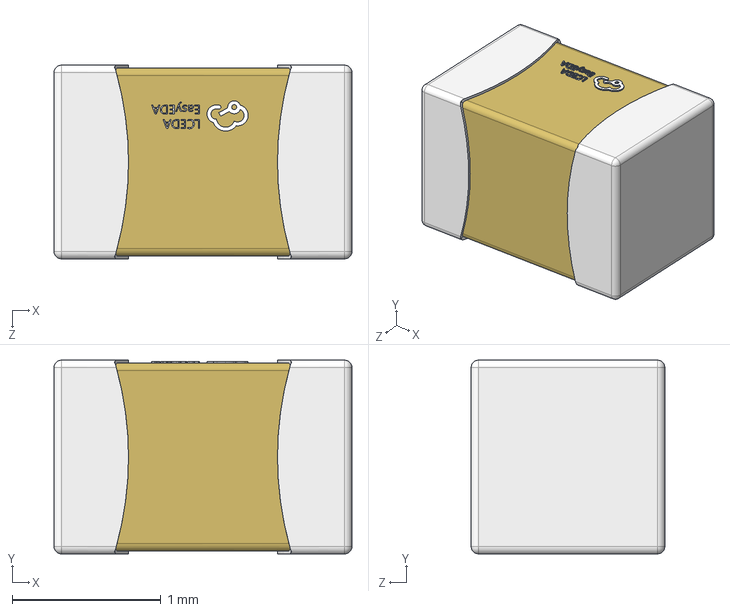
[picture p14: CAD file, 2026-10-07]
imports/supplier/CC0805KRX7R9BB104/CC0805KRX7R9BB104.step
2.00 x 1.30 x 1.30 mm

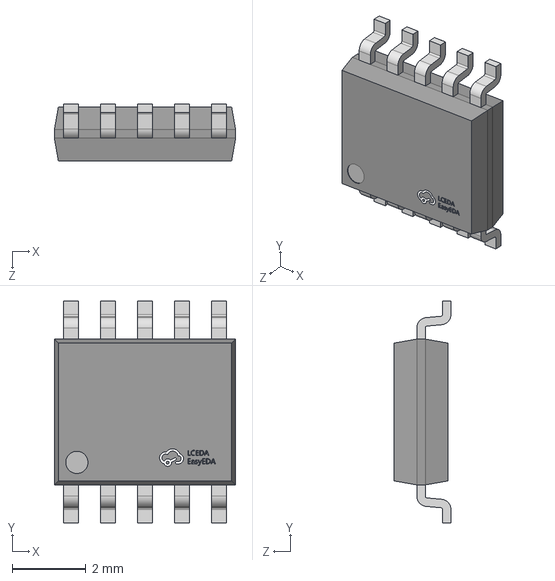
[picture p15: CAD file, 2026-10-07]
imports/supplier/CH224K/CH224K.step
4.90 x 6.00 x 1.54 mm

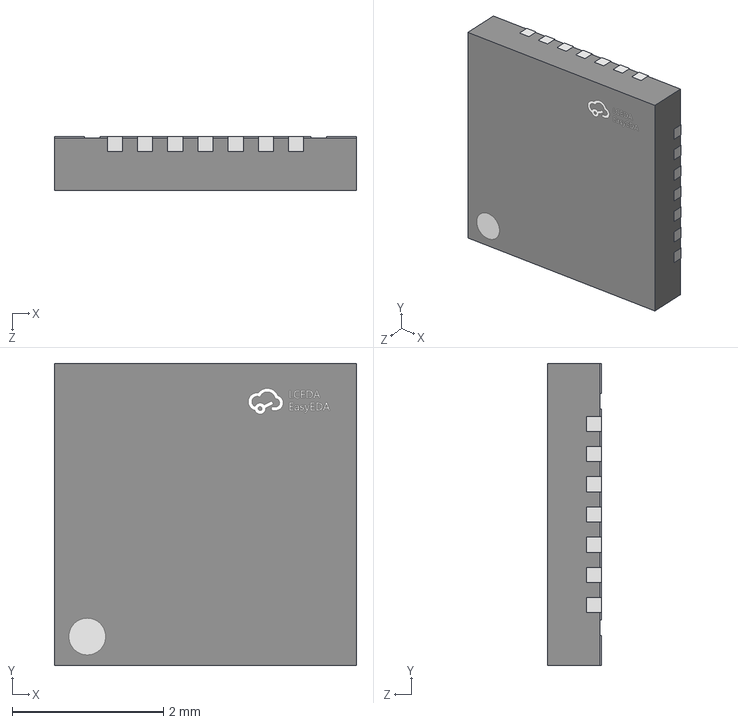
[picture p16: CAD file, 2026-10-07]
imports/supplier/CH32X035G8U6/CH32X035G8U6.step
4.00 x 4.00 x 0.721 mm

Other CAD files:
imports/supplier/A4988SETTR_T/A4988SETTR_T.obj
imports/supplier/A_0402WGF4701TCE/A_0402WGF4701TCE.obj
imports/supplier/A_0603WAF1001T5E/A_0603WAF1001T5E.obj
imports/supplier/A_0603WAF1002T5E/A_0603WAF1002T5E.obj
imports/supplier/A_0603WAF1003T5E/A_0603WAF1003T5E.obj
imports/supplier/A_0603WAF2202T5E/A_0603WAF2202T5E.obj
imports/supplier/A_0603WAF3902T5E/A_0603WAF3902T5E.obj
imports/supplier/A_0603WAF5101T5E/A_0603WAF5101T5E.obj
imports/supplier/B5819W_SL/B5819W_SL.obj
imports/supplier/CC0603KRX7R9BB104/CC0603KRX7R9BB104.obj
imports/supplier/CC0805KRX7R9BB104/CC0805KRX7R9BB104.obj
imports/supplier/CH224K/CH224K.obj
imports/supplier/CH32X035G8U6/CH32X035G8U6.obj
imports/supplier/CL10A105KB8NNNC/CL10A105KB8NNNC.obj
imports/supplier/CL10B103KB8NNNC/CL10B103KB8NNNC.obj
imports/supplier/CL10B224KA8NNNC/CL10B224KA8NNNC.obj
imports/supplier/CL21A475KBQNNNE/CL21A475KBQNNNE.obj
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

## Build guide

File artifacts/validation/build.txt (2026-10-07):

> NEMA14_CH32X035G8U6@1.0.6 check
> bun scripts/check.ts

{
  "traceCount": 351,
  "currentLimitAmps": 0.350765306122449,
  "errors": 0,
  "warnings": 0
}

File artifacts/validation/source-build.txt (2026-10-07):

> NEMA14_CH32X035G8U6@1.0.6 source:check
> bun scripts/build.tsx --unrouted

Rendering NEMA14 with tscircuit local autorouter…
{
  "elements": 2136,
  "traces": 0,
  "errors": []
}

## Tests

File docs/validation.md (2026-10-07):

# Saved-board validation

Run `npm run typecheck`, `npm run source:check`, `npm run build`, `npm exec -- tsci check artifacts/board.circuit.json`, `npm exec -- tsci check schematic-placement artifacts/board.circuit.json`, `npm run export`, and `npm run shorts`. Source compilation writes its separate unrouted artifact; build/check/render use the saved delivery copper. `scripts/sync-presentation.py` merges source/schematic metadata with assertions that saved PCB records and physical pin/net identities are retained.

`artifacts/validation/` contains actual command outputs. `artifacts/drc-report.json` contains full checks including power/ground pin attributes. Passive connector/crystal footprints are classified by physical role for ERC. `artifacts/physical-connectivity.json` independently checks the copper islands with Shapely geometry. Gerber shorts are checked on every copper layer at 100 pixels/mm. These are software checks and do not establish physical flashing, assembly, rear fit or thermal behavior.

## Browser schematic review

Run `python3 scripts/schematic-review-ui.py` for a read-only browser UI that displays native tscircuit A4 SVG pages beside actual `tsci check schematic-placement` and DRC findings. The browser review visits every numbered A4 page; screenshots and its result JSON are in `artifacts/validation/`.

The standalone tscircuit IDE was also launched. In this environment its PCB pane cannot obtain a WebGPU adapter, and the Schematic tab is disabled for the saved circuit-JSON selection. The review UI provides the native SVGs and CLI analysis without requiring GPU access; it is a project review tool, not the IDE's disabled schematic analyzer pane. External telemetry/CDN requests blocked by the cloud allowlist are recorded as environmental limitations.

See [USB programming](usb-programming.md). All fitted components now have exact supplier imports and OBJ/STEP assets; consult the reference-level import report.

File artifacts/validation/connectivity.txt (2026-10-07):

{
  "checkedNets": 33,
  "disconnectedNets": [],
  "allCopperLayersChecked": true,
  "nativePolygonAndSlotGeometry": true,
  "sha256": "85d545ee603fda6e4acecc893c84e608719a590ea8ebd1e66e7ec00a19c81107"
}

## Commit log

2026-10-07 Add NEMA14 CH32X035G8U6 USB-C PD controller and saved routing
    [bom.csv, freerouting-input.dsn]
2026-10-07 Prepare registry publication and normalize generated text artifacts
    [bom.csv]
2026-10-07 Align USB-C openings with board edges and publish NEMA14 project
    [bom.csv]
2026-10-07 Add verified supplier CAD and annotated A4 schematics
    [CC0603KRX7R9BB104.obj, CC0603KRX7R9BB104.step, CL10A105KB8NNNC.obj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]
2026-10-07 Serve CAD assets from the existing public GitHub repository
2026-10-07 Add CH32 USB boot entry and validate saved motor controller layout
    [A_0402WGF4701TCE.obj, A_0402WGF4701TCE.step, bom.csv]
2026-10-07 Import every fitted component from JLCPCB with native footprints and CAD
    [A4988SETTR_T.obj, A4988SETTR_T.step, A_0402WGF4701TCE.obj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]
2026-10-07 Record verification of published board and supplier model assets
2026-10-07 Publish root circuit entry point with checked circuit JSON
2026-10-07 Publish native circuit JSON build output with include-dist
2026-10-07 Review power copper and protect motor voltage sensing
    [bom.csv]
2026-10-07 Record public verification of reviewed board files
2026-10-11 Verify exact NEMA14 mounting and USB clearance with native CAM evidence
2026-10-11 Fit same-edge USB-C ports inside 35mm NEMA14 mounting envelope
2026-10-11 Restore fitted reference JST PH motor connector with verified native CAM and CAD
2026-10-11 Update restored JST release documentation and board hash
2026-10-11 Record current JST copper counts and public verification
2026-10-11 Refresh independent Gerber renders for fitted JST board
2026-10-12 Add reference feedback circuits and verify same-edge NEMA14 prototype
2026-10-12 Record verified public v1.5.0 circuit and Gerber files
2026-10-12 Refresh native component and placement tables for CH32 prototype
2026-10-12 Organize CH32 schematic into five verified functional sheets
2026-10-12 Record verified public CH32 v1.6.0 schematics and drills
2026-10-12 Increase resistor edge clearance on every CH32 board side
2026-10-12 Record verified public CH32 v1.7.0 resistor clearances
2026-10-13 Validate order paste schema and disclose inherited CAD metadata findings
2026-10-13 Include all USB shell and JST joints in assembly review plan
2026-10-13 Use top-side assembly and reference JST-SH with standard USB-C schematics
2026-10-13 Bind published schematic-analysis evidence to the current validated board
2026-10-13 Separate standard USB-C symbol labels and require empty schematic diagnostics
2026-10-13 Record verified public v1.8.2 CAD and JLCPCB review files
2026-10-14 Use upright USB-C, standard vias and optional bottom encoder
2026-10-14 Pin locally imported CAD assets in the public package
2026-10-14 Clarify upright connector clearance and pending assembly process review
2026-10-14 Record verified public v1.10.1 prototype files
2026-10-14 Qualify six-sheet schematic captions and final prototype release
2026-10-14 Record verified public v1.10.2 prototype files
2026-10-14 Connect all NEMA14 CH32 nets and qualify opposite-edge PCB
2026-10-14 Document distinct current and historical preservation comparisons
2026-10-14 fix: refresh CH32 assembly concept and bound registry uploads
2026-10-15 Add complete routed motor assembly and verified hardware preview
2026-10-15 Record verified assembly releases and bound registry uploads
